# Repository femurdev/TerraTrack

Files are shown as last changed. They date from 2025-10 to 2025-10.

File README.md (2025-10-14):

# 🚀 TerraTrack
```
"""
AI-powered robotics project inspired by the game TerraTech.
Built for learning, experimentation, and competition.
"""
```

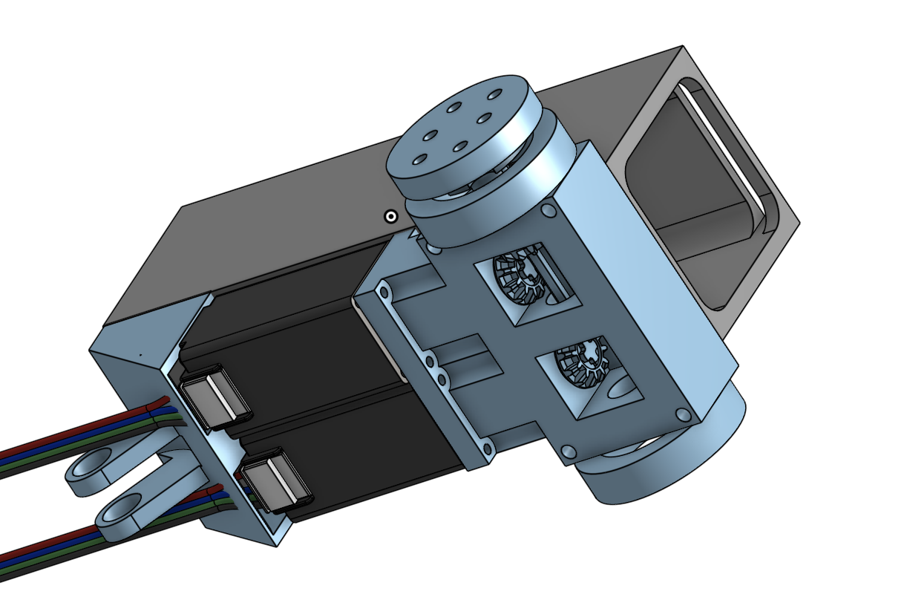
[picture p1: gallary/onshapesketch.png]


## 🧠 Overview

TerraTrack is an ongoing robotics project that explores the intersection of **AI**, **embedded systems**, and **mechanical design**.  
The goal is to create a modular, intelligent platform capable of running on both **ESP32** and the upcoming **Arduino × Qualcomm** systems.

While some design details are being kept private until the competition season wraps up, this repository captures the learning process, designs, and build journey so far.

## ⚙️ Current Focus

- 🤖 Basic AI-driven motion and control (early stage)
- ⚡ Compatibility across ESP32 and Arduino hardware
- 🧩 Modular mechanical design for quick rebuilds
- 🔧 Open workflow using Onshape + Blender
- 🔋 Safe custom power system with 3D-printed enclosure

## 🛠️ Build Journal

Read the full project journal on **Hack Club Blueprint**:  
👉 [TerraTrack Project Journal](https://blueprint.hackclub.com/projects/485)

Below is a summary of progress so far.

### 🧩 Early Prototyping (v1–v2)
- Designed and printed first chassis, gearbox, and axles using **Onshape** and **Blender**.
- Fought with 3D printers, burned out an early prototype, and learned about safe wiring.
- Added a toggle switch after discovering how easy it is to cause “accidental smoke.”

### ⚙️ Iteration & Redesign (v3–v4)
- Reinforced axles with skateboard bearings to prevent snapping.
- Added gearbox covers and improved weight distribution.
- Created a new battery pack with secure housing.
- Introduced a rear “butt” assembly for smoother movement.
- Countless printing and soldering sessions to get it all together.

### 🔥 Failure, Fatigue, and Fire
- Motor drivers finally responded after days of debugging—then failed again.
- Tried increasing torque through firmware; resulted in actual smoke.
- Damaged stepper motors and drivers, currently sourcing replacements.
- Despite the setbacks, communication and control logic now partially work.

## 🧰 Tools & Components

| Category | Tools / Components |
|---|---|
| CAD / Modeling | Onshape, Blender |
| Hardware | ESP32, TMC2209 Motor Drivers, Stepper Motors |
| Fabrication | 3D Printing (Da Vinci Jr., Bambu X1), Soldering |
| Software | Arduino IDE, C++ |
| Other | PLA Filament, Custom Battery Enclosure, Bearings |

## 💡 Lessons Learned

- Iteration is everything — no version is wasted.
- Documentation helps recover from mistakes faster.
- Always isolate power before soldering or testing.
- Fire safety isn’t optional.
- Building with limited resources teaches patience (and creativity).

## 🧭 Next Steps

- Rebuild chassis with stronger materials.
- Improve torque and motor control code.
- Add modular battery swapping and safety systems.
- Integrate AI motion logic once hardware is stable.
- Seek funding for replacement parts (~$120 total).

## 📷 Gallery

| Stage | Image |
|---|---|
| Gearbox v2 | Screenshot 2025-10-13 at 6.09.27 PM.png |
| Battery Pack v1 |  |
| Gearbox Rebuild | Screenshot 2025-10-13 at 9.15.03 PM.png |
| Final v2 Mockup |  |

## 💬 Author

TerraTrack is a student robotics project developed as part of a Hack Club event.  
The aim is to learn, experiment, and document the process honestly — including the mistakes, smoke, and all.  

Follow progress or share ideas via [Hack Club Blueprint](https://blueprint.hackclub.com/projects/485).

## ⚠️ Note

Some key parts of the system are withheld until after the competition season to prevent duplication.  
Full technical documentation will be released once the event concludes.

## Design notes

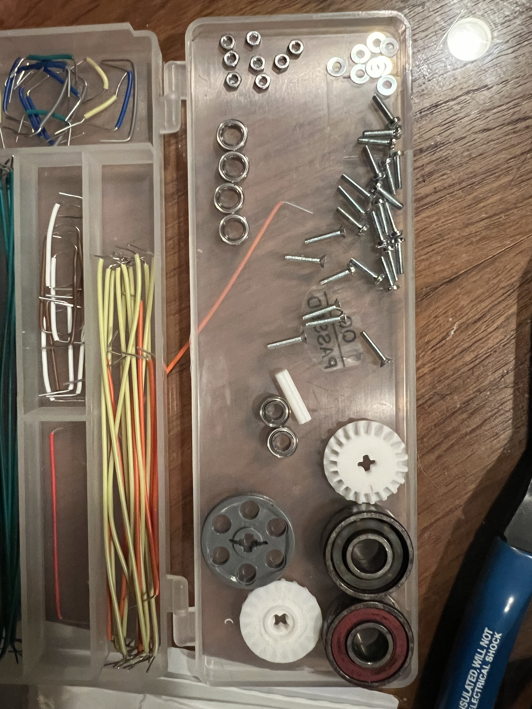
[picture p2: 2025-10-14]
gallary/hardware.jpeg

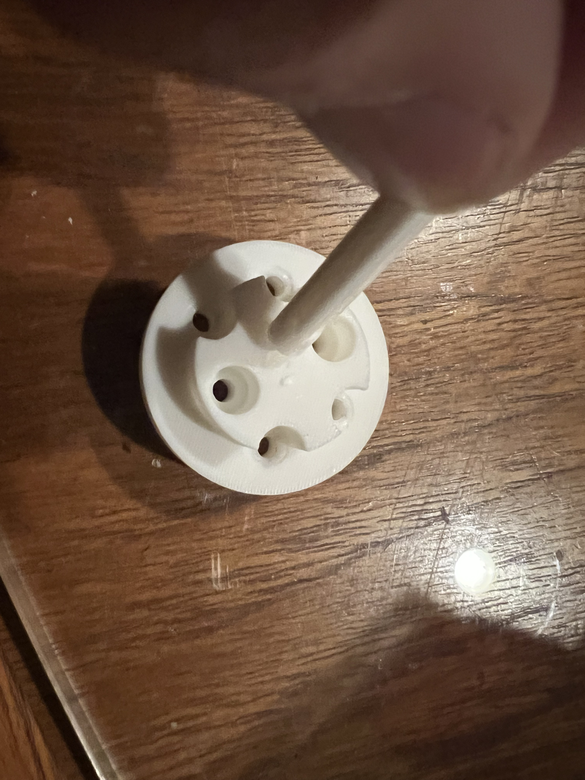
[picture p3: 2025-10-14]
gallary/brokenAxel.jpeg

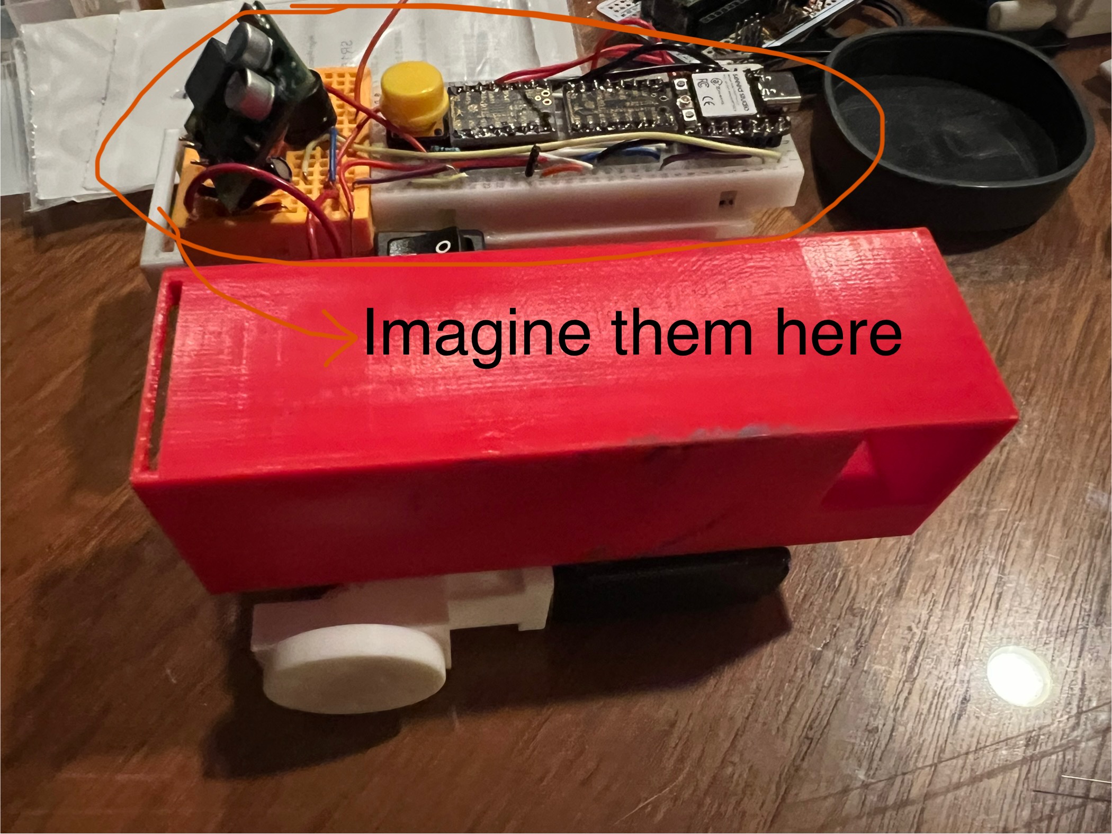
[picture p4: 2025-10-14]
gallary/finalv2.jpg

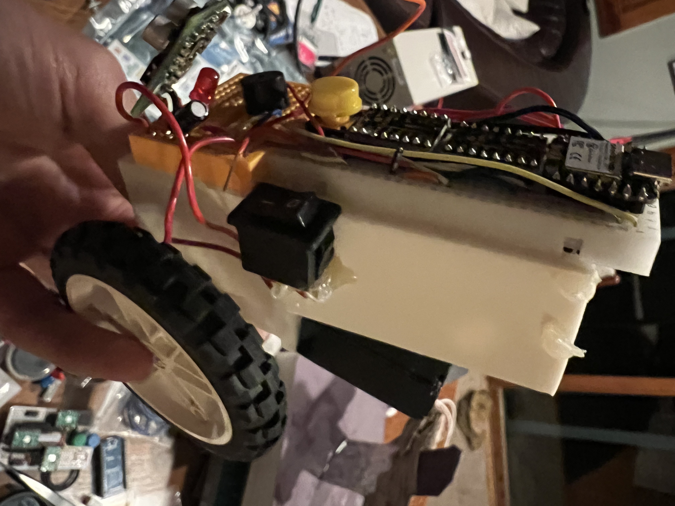
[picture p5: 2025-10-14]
gallary/recreation.jpeg

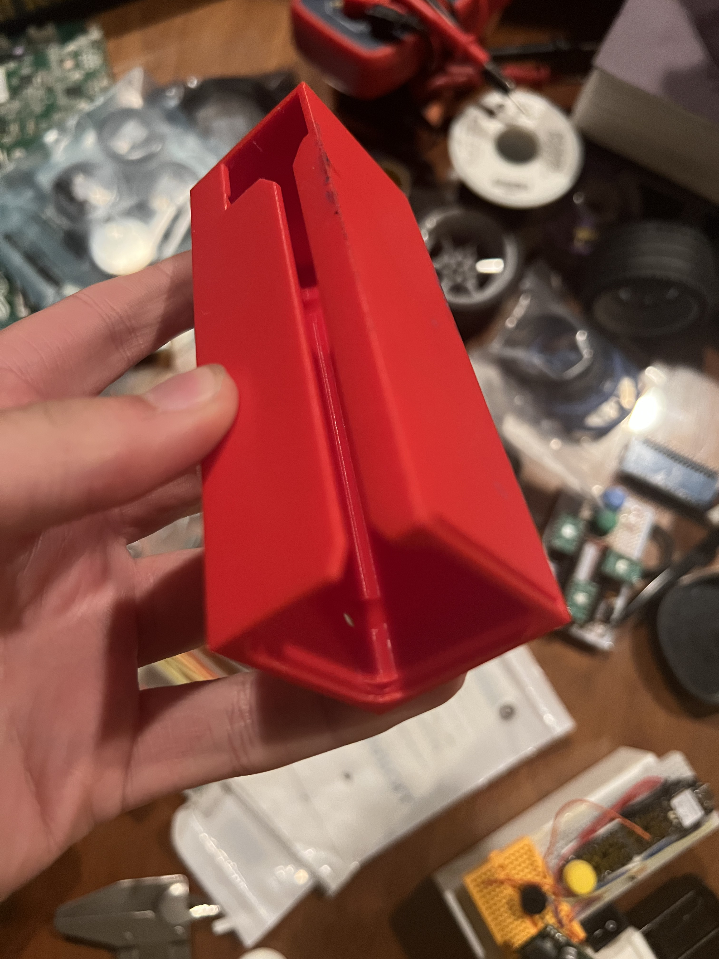
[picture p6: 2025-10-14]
gallary/battery2.jpeg

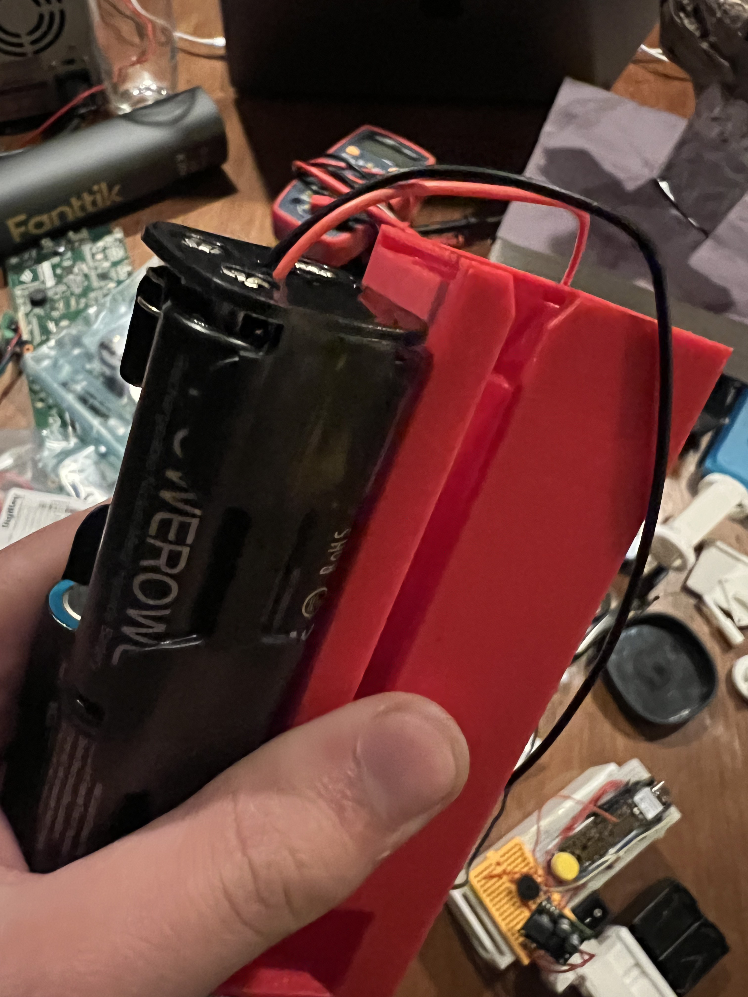
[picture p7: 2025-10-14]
gallary/battery1.jpeg

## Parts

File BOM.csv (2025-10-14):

Item | Quantity | Part Number | Description | Manufacturer | Vendor | Unit Price (USD) | Total Price (USD) | Notes | Product Link
1 | 2 | SS2421-5041 | Stepper Motor, Bipolar, 1.8°, 4.5V, 1.2A, 42mm Frame | Sanyo Denki | Digi-Key | 45.74 | 91.48 | Primary stepper motors | https://www.digikey.com/en/products/detail/sanyo-denki-sanmotion-products/SS2421-5041/13533469
2 | 2 | 3768 | DRV8434S SPI Stepper Motor Driver Carrier, 2A Max Current Limit | Pololu Robotics & Electronics | Pololu | 13.95 | 27.9 | Motor driver boards | https://www.pololu.com/product/3768
 |  |  | Total Estimated Cost (USD) |  |  |  | 119.38

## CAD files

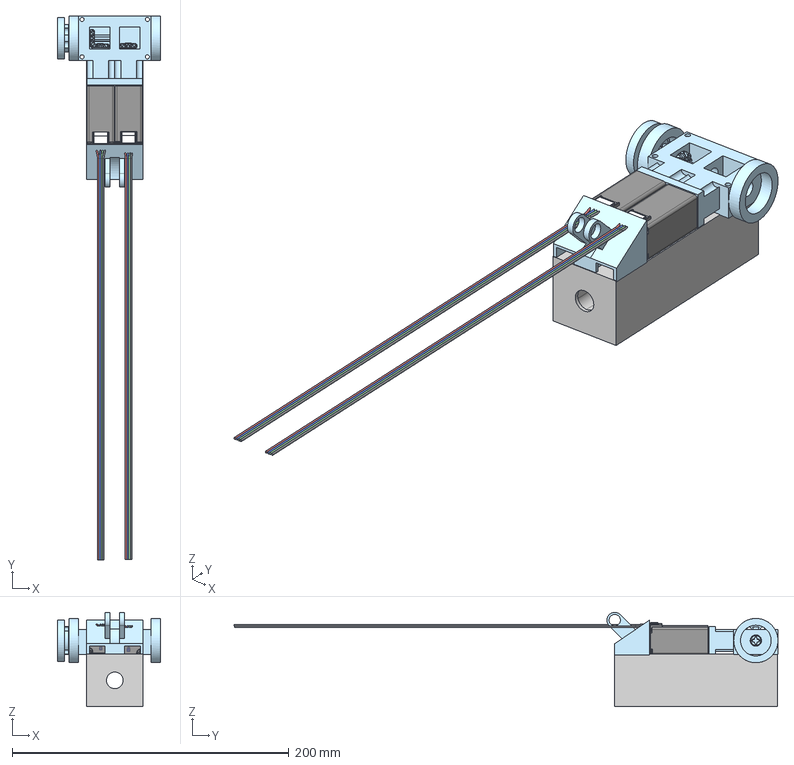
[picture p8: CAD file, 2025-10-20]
Assembly 1.step
74.5 x 393.2 x 68.1 mm
SY20STH42-0804A x 2

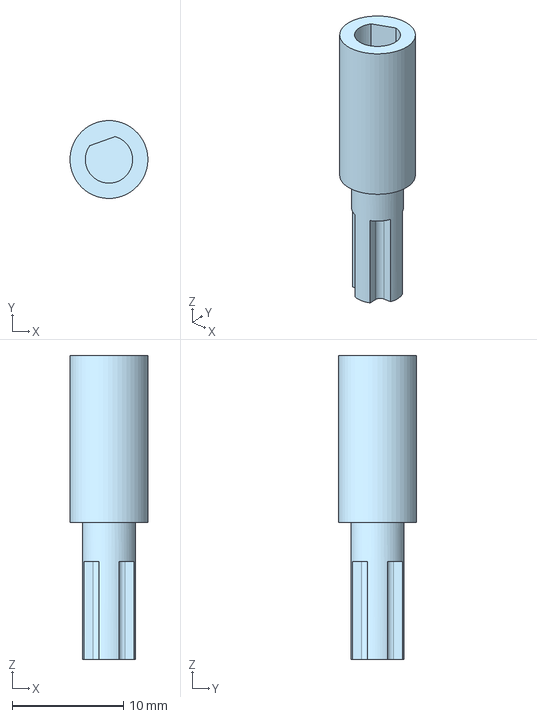
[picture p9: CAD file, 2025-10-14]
models/4vSTEPFiles/v4FinalMotorAdapter.step
6.99 x 7.00 x 27.3 mm

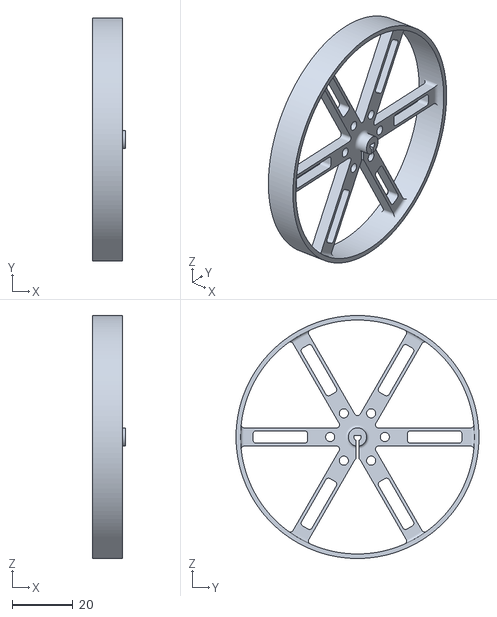
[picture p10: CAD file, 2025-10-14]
models/imports/Pololu wheel 90mm x 10mm - Pololu wheel 90mm x 10mm v1.stl
11.0 x 80.0 x 80.0

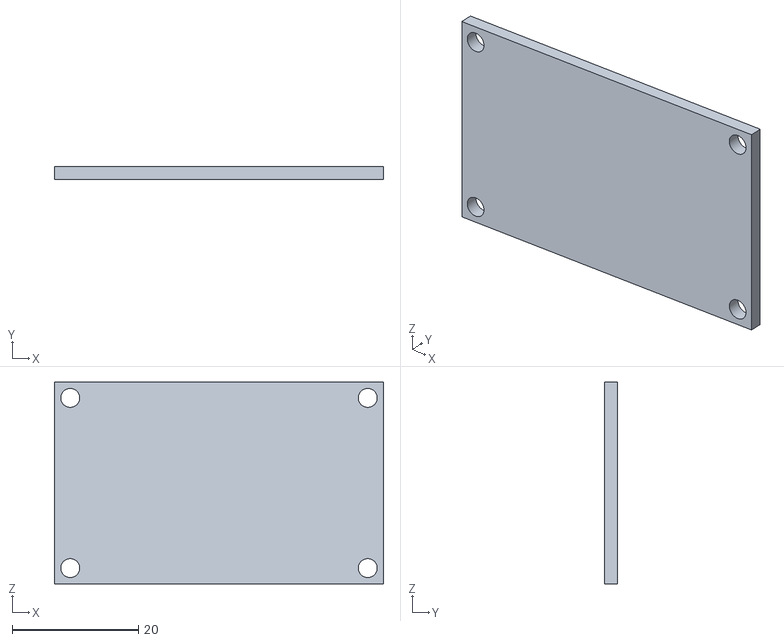
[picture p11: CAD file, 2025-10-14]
models/v4/v4gearcover.stl
52.2 x 2.00 x 32.0

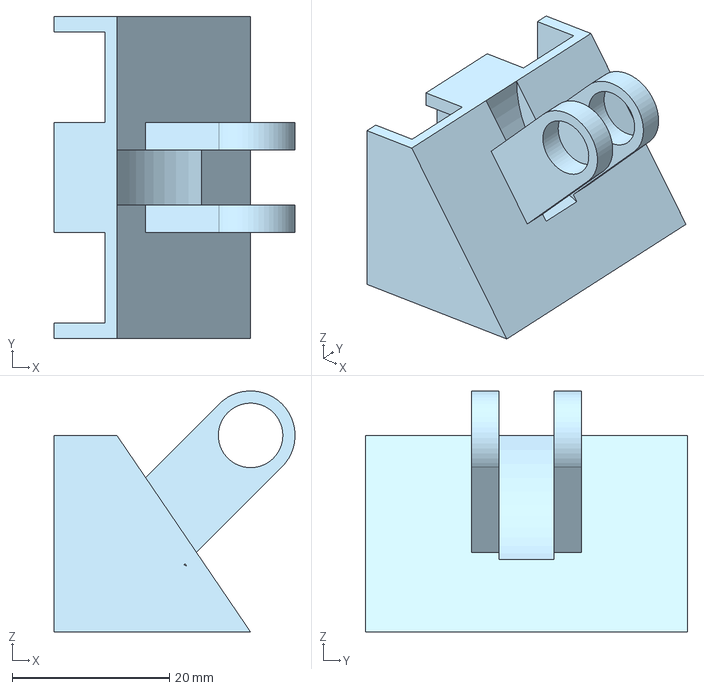
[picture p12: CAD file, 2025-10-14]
models/4vSTEPFiles/v4FinalButt.step
30.6 x 41.0 x 30.6 mm

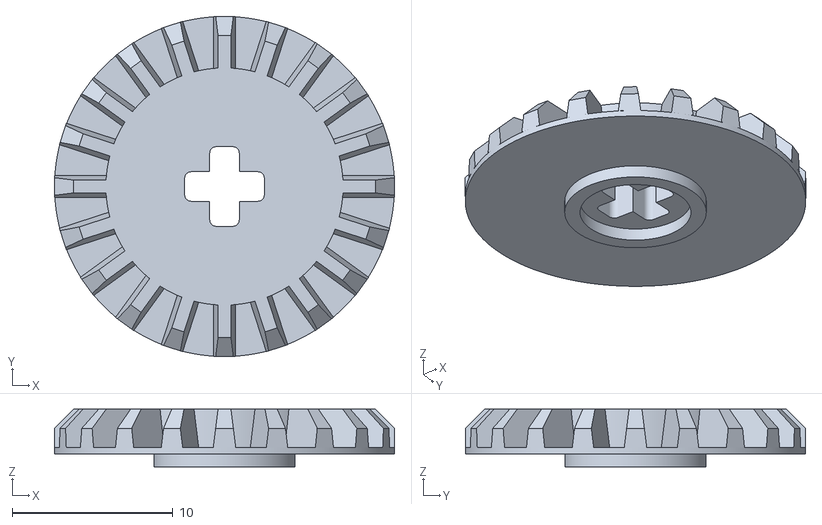
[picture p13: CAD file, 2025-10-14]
models/imports/20t.stl
21.2 x 21.2 x 3.60

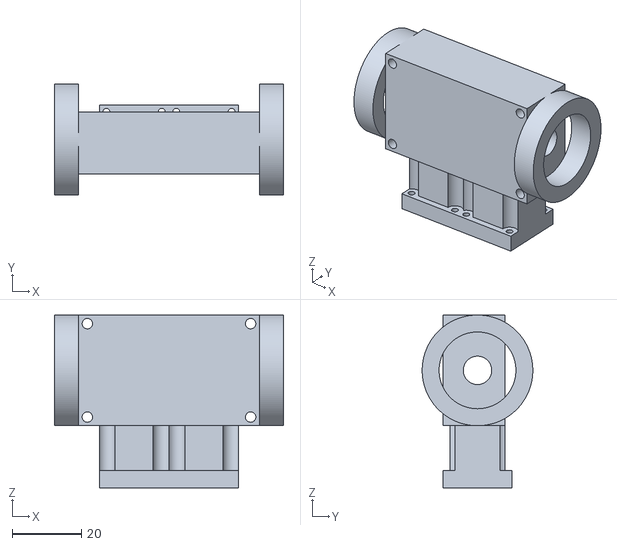
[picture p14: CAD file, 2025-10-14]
models/v4/v4gearbox.stl
66.2 x 32.0 x 50.0

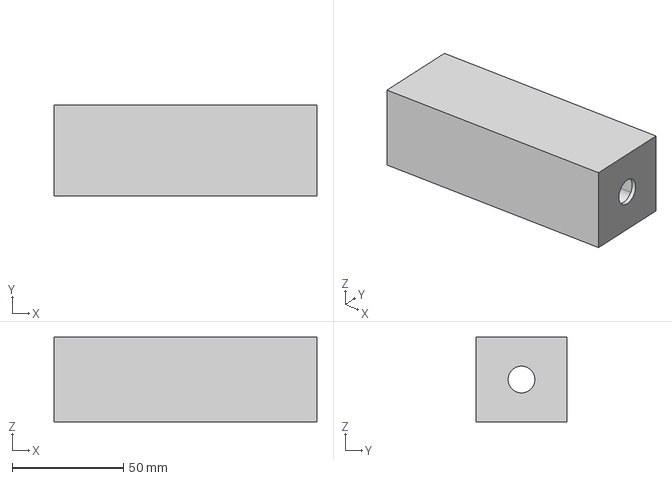
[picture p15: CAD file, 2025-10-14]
models/4vSTEPFiles/v4FinalBatteryHolder.step
118.0 x 41.0 x 38.0 mm

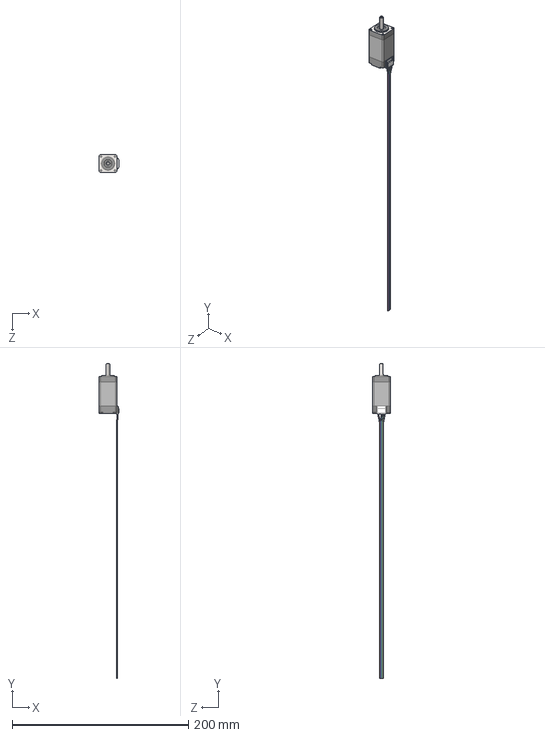
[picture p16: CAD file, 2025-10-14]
models/imports/SY20STH42-0804A.step
22.3 x 357.5 x 20.0 mm

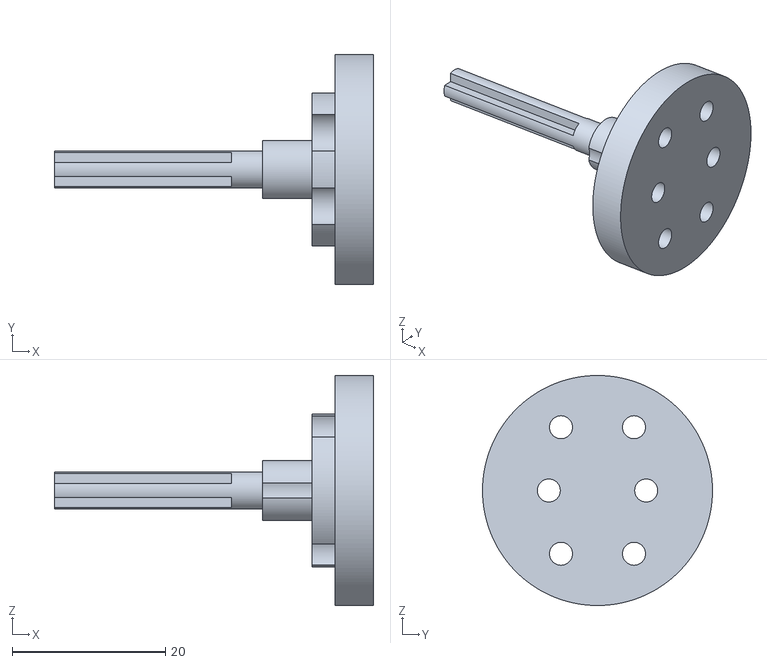
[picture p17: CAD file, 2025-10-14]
models/v4/v4wheel.stl
41.6 x 30.0 x 30.0

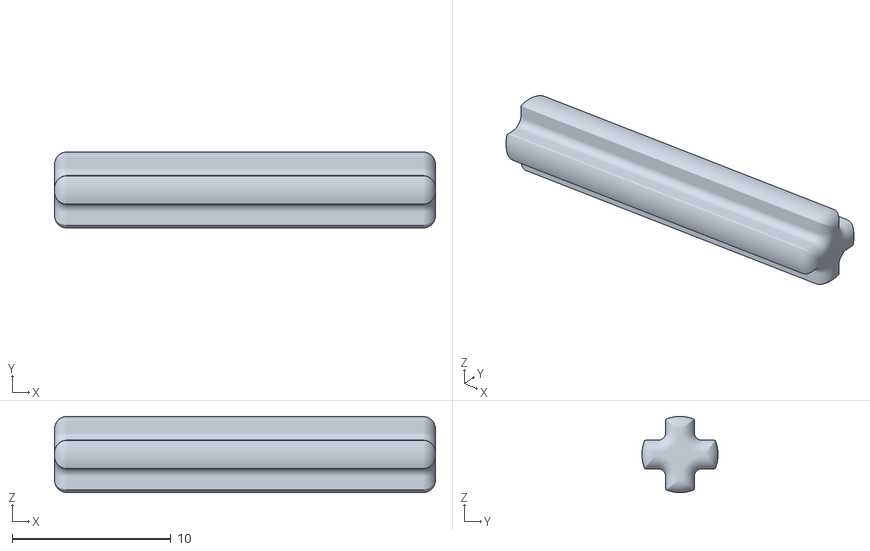
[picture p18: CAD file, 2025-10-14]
models/imports/4519 DkStone Technic Axle 3 - Part 1.stl
24.0 x 4.80 x 4.80

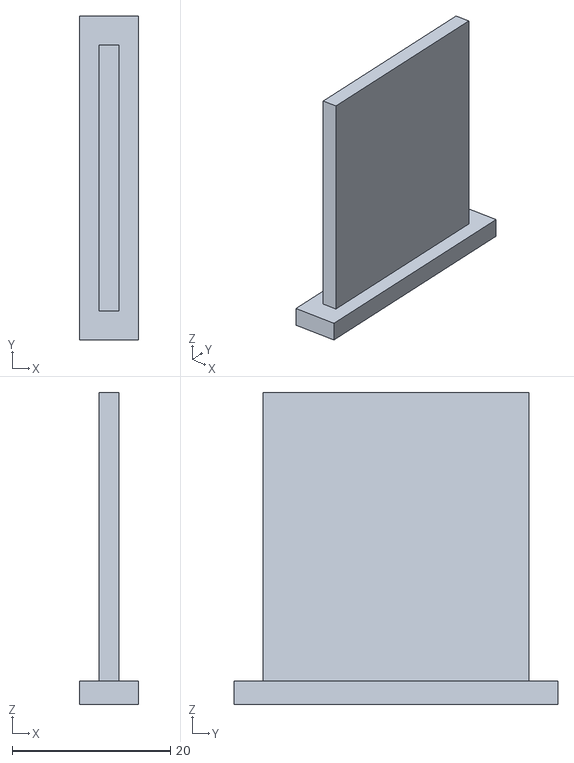
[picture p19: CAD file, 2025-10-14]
models/v4/v4battblock.stl
7.50 x 41.0 x 39.5

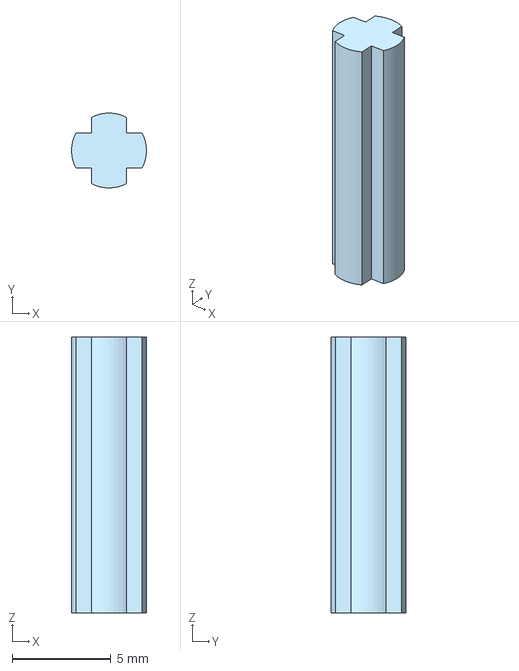
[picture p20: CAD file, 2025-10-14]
models/4vSTEPFiles/v4FinalShavedAxel(for butt).step
3.80 x 3.80 x 14.0 mm

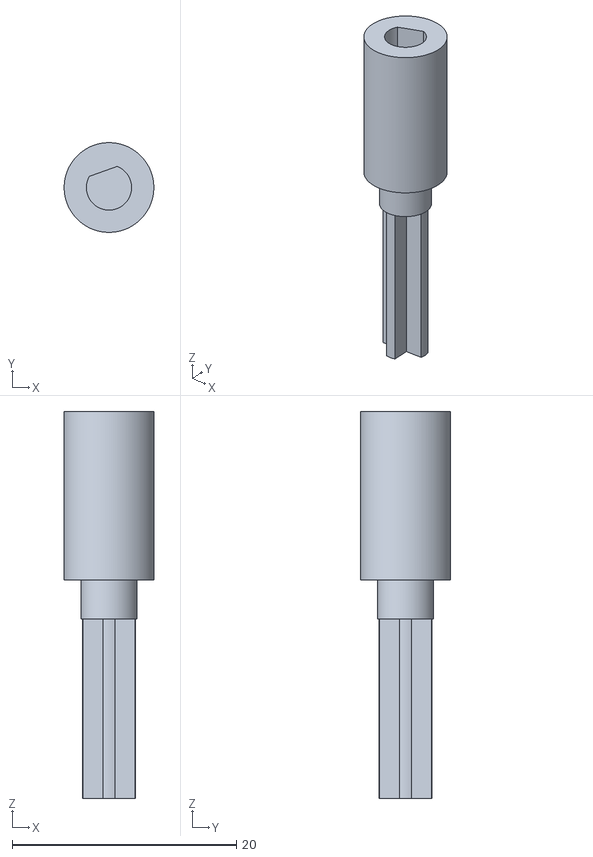
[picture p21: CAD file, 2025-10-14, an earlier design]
models/v1/yayayayaya.stl
8.00 x 8.00 x 34.5

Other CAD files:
models/4vSTEPFiles/v4FinalGearboxDoor.step
models/4vSTEPFiles/v4FinalAxel.step
models/4vSTEPFiles/v4FinalGearbox.step
models/4vSTEPFiles/v4FinalBatteryDoor.step
models/v1/Part Studio 1 - Part 1(6).stl
models/v1/Part Studio 1 - Part 1(7).stl
models/v1/Part Studio 2 - Part 1.stl
models/v1/Technic_Gear_Single-Sided.stl
models/v2/v2gearbox.stl
models/v2/v2mot.stl
models/v2/v2wheel.stl
models/v3/v3backaxel.stl
models/v3/v3batt.stl
models/v3/v3butt.stl
models/v3/v3wheel.stl

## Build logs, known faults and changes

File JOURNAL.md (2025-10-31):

<!--
  ===================    !!READ THIS NOTICE!!   ====================
  DO NOT edit this file manually. Your changes WILL BE OVERWRITTEN!
  This journal is auto generated and updated by Hack Club Blueprint.
  To edit this file, please edit your journal entries on Blueprint.
  ==================================================================
-->

## 10/16/2025 7:16 AM - Prototyping, routing, discovering, and lighting things fire.  

### Old Recount

This is to catch everyone up to the current state of things. I have mark one completed at this point but much to my dismay, it does not work. I have managed to burn it and can not afford any more components for the time being. 
## Here's a quick recap of what happened: 
Learned on shape and created v1 (and technically v2, but that was small). 
### Shopping and Physics: 
I ran some basic demos thing for my math. Look at what I have remaining from this step: Screenshot 2025-10-13 at 8.47.01 PM.png 
This translated to snooping arr round for parts shortly after, which is a headache to match steppers and motors. 
### Onshape & Blender!! Motor Connection v1 (3+ hours, I'm new to Onshape at this point): Screenshot 2025-10-13 at 6.07.49 PM.png Axel v1 (1 hour, getting better): Screenshot 2025-10-13 at 6.09.04 PM.png 
### Gearbox v2 
(2 hours again, multiple axies and offsets are hard for begining): 
Screenshot 2025-10-13 at 6.09.27 PM.png  The gearbox took some hardware too.  Battery container v1 (4 hours, I used blender to try it out, don't reccommend):   
### Fabrication.
The printer broke like 4 times, at this point and I tried to fix the sucker for 6+ hours (not included here for obvious reasons.) (da Vinci Jr. XYZ printer from the cretaceous) Off to the library to use their X1. Continued in CAD. Took an hour or so of changing nozzles and filament + glusticking. There were a few problems with this first batch. The most blaring is that the Axels repeatedly snapped. It was at some time at the 17-ish hour mark of this project when I started soldering my motor drivers and ESP32. This in of itself took two hours to find, set up, dismantle, and store. I was spending the next hour-ish gluing the parts together when suddenly, 
_Sparks!_ _Smoke!_ _Panic!_. 
I don't have a photo of this but imagine ElectroBoom strumming his electric guitar. I discovered that a talent of mine that made this fire followed me here, complete idiocy. I had left the barreries in the capsule while I contined making other parts of the setup. Lickily, nothing was destroyed but this made me realize the need for a switch. Jump to an hour later where I am found dismantling an old electronic board from I don't even know what. It had a toggle switch rated for 3 amps, good enough for me. Stay tuned for part 2 of the catch up, we're only 4 days (only about 23 hours of which were on this project) into this mess at this point. Here's a recreation of the state of the bot at the end of this. Sorry about this taking so much time, I'm juggling cleaning and teaching my brothers about electronics as I build this. Its part of a larger team event so there are also numerous hours of discussion not mentioned here.   

## 10/16/2025 7:17 AM - Solving problems and innovation (v3 & v4 of inital design)  

# Old Recount
We're off to the races. I've got a basic setup and body, but there's something nagging at me, my bot, and my soul: getting it working. I constructed the bot completely, top to bottom, complete with hot glue connections that would have outlived the sun. But it wasn't to be. Like all engineering endeavors, there was a laundry list of glaring issues, many of which I honestly thought I could ignore. Here, I think I'll do a picture by picture list of improvements that I made to my design: 
### The Axels. 
They look so thin and have just 3 mm of PLA Lego axel extrusion to hold them upright. Of course, they were going to snap. I added in some more joints and another 2 bearings onto the parts list, one for each side. Took about 4 hours to decide how to fix this and tear the bearings out of an old skateboard. Screenshot 2025-10-13 at 9.15.21 PM.png 
### The Gearbox. 
I dropped it on the floor and everything came out. Furthermore, I added a cover. Now, if it breaks, I won't know immediately (bad) and have the peace of mind that I haven't lost parts. (good) a couple of other things include the insane triple bearing design to try to take as much wight and distribute it as evenly as possible. (This is, and is still IMO valid madness) Each assembly took an hour and I did this a lot as I made changes. Screenshot 2025-10-13 at 9.15.03 PM.png 
### The Battery Pack. 
The battery pack that was initially made was too small for the pack once I actually added the batteries. There was no real other problem. I also added a cover so that way they can't fall out now. This took a bit to dseign. Screenshot 2025-10-13 at 9.15.48 PM.png 
### The Butt. 
Before, I didn't have any way for the car to drag itself along. This butt component allows me to add a Lego wheel and a few bearings to let the car glide seamlessly over the floor. I used layer designing for this, and it worked to an absolute charm, except for the fact that it was completely new to me and therefore took about 3 hours to perfect once I settled on an idea. Screenshot 2025-10-13 at 9.17.05 PM.png 
### Fabrication. 
3D printing once again took ages and soldering it a pain as always. I got the circuit back together, transferred bodies and put enough glue to make the gods envy it. To clear up any confusion between v3 and v4, v3 was when I added the bearing and nothing else. 4v came just after and was much more intense of a rebuild so that is what is here. ### Gearboxes are impossible! Sorry for having to say this again, they just take _SEVERAL HOURS_ to assemble each and every time. I dislike this very much. 
### OMG ITS PROGRAMMING, EVERYBODY RUN!!! 
I normally love programming, but there's something about this particular project that just made it impossible. I don't know what was about these particular motor drivers, but I can't get them to even budge. Furthermore, I found a sneaky pin that I needed jumpers for, but even that didn't solve my problems. Sorry, no complete assembly because I dismantled it and want to save the recreation of it for my next post. This took the **majority of my time this week**, even during school, where I wrote potential interactions that I only hoped would work. Well, that was awful. I'd just sunk a whole week and a half into this thing, and I'm stumped. No Fires this time (1 nature — 1 me)  

## 10/16/2025 7:18 AM - Failure, Fatigue, and Fire  

## Old Recount
This is the final update to get you up to speed on this project. _**Finally**_ But it isn't over. 
### The changes.
The whole thing is dismantled. Seriously. Let me elaborate. When I last left off on this story, I was still discussing the fact that I was stuck on programming this sucker. Well, after another two days when I told myself, just one more try, just one more try, MAGIC. The motors suddenly locked up. 
### What this means. 
This means that I have successfully told my motor controllers to turn on. _Big whoop!_ 
Seriously, this is what I couldn't get my motors to do for the past two weeks at this point. Now, they were awaiting commands, commands that were no longer hours to debug why it wasn't connecting, just commands that would work now that the communication was working. So I told them to spin in one circle while I held the bot in the air. They did that. I put it on the gound. 
_*crickets*_ 
I heard nothing. The motors tuned out to either be too weak to actually tun the wheels or something much worse is happening (that to this that I don't know). I used much of my remaining time that day trying to get it to move. The next day, I continued, I brought it home, I did everything. 
_It. Wouldn't. Budge._ 
I read online that adding some code could make them stronger:
```
  driver1.setup(Serial1, SERIAL_BAUD, TMC2209::SERIAL_ADDRESS_0, UART_PIN, UART_PIN);
  driver1.setRunCurrent(100);
  driver1.setHoldCurrent(0);
  driver1.setMicrostepsPerStep(1);       // full step for max torque
  driver1.disableStealthChop();          // spreadCycle = stronger torque
  driver1.enable();
```
### Big mistake.
The thing started smoking as soon as I tuned it on, slowly at first, then pluming outwards. The robot had lost the magic smoke. We all know what that magic smoke means. Someone, on board, has died. Most of the time, only the factory can put said magic smoke back inside the components, and I know this truth. 
_Small issue:_ the components that burned out were the only steppers I had, which cost 60 dollars before tariffs but are now 120 dollars. I have a plan now to avoid this insane bill, but I still need the funding for this project. I have 2 motors that cost 40 dollars each and 2 drivers that sum to 40 dollars, about 120 in total. The new chassis requires a new roll of filament to make. Please help I'll leave you with this recreation:   

## 10/18/2025 12:55 PM - Ideation, Shopping, and Physics  

### Old Recount - handwritten this time. (feels like walking into engineering English class)
This is to catch everyone up to the current state of things. I have mark one completed at this point but much to my dismay, it does not work. I have managed to burn it and can not afford any more components for the time being. Here's a quick recap of what happened.
Learned Onshape and created v1 (and technically v2, but that was small adjustments). 

### Shopping and Physics: 
I ran some basic demos thing for my math. Look at what I have remaining from this step: Screenshot 2025-10-13 at 8.47.01 PM.png 
This translated to snooping around for parts shortly after, which is a headache to match steppers and motors. 

## 10/18/2025 12:55 PM - Onshape!!  

I began my development by creating a d-shaft to Lego axel connection. My plan was to use bevel gears from a Lego kit to translate the motion from the motors 90 degrees. I swear that my sketches are valid, but it just don’t care. I listed everything out but hack club wants me to spit it up, so here we go!

### Motor Connection v1 (3 hours as I'm new to Onshape at this point): 

Screenshot 2025-10-13 at 6.07.49 PM.png 

## 10/18/2025 1:01 PM - Continued development  

### Axel v1: 

I continued uncovering how to use Onshape and came up with this design. When I first made it, I don’t know how I missed the glaring issue that the axle is so thin. This was updated in a later revision, but _still_. Additionally, this revision relied only on one bearing, something that I still don’t believe that I did.  
Screenshot 2025-10-13 at 6.09.04 PM.png 

## 10/18/2025 1:02 PM - Again, more Onshape yet  

I continued to work on fleshing out this idea. I was gaining traction on how to use Onshape at this point.

### Gearbox v1

4 hours again, multiple axis and offsets are hard for beginning users. I come from a background of blender and animation models, not CAD beyond Tinkercad. I used to build my projects purely off of blender and other files, but that is just impossible for me sometimes.  
Screenshot 2025-10-13 at 6.09.27 PM.png    

## 10/18/2025 1:02 PM - Hardware  

The gearbox took some hardware too. Most of this was scavenged from some old projects, skateboards, and even from an old 3d printer. These include bearings, some screws and the switch for the bot (not pictured.) This was a quick process all except for the hour and a half trip up to ace hardware form $6 of M2 screws.    

## 10/18/2025 1:03 PM - Battery Pack  

Battery container v1- 4 hours, I made this when I originally leaned blender to try it out, don't recommend for engineering models. I redesigned the model in Onshape after 4 hours of fooling around in blender. Keep in mind I still haven’t actually printed any of this.    

## 10/18/2025 1:21 PM - Da Vinci v. Me / Praying for an X1  

The printer broke like 4 times, at this point, and I tried to fix the sucker for over 2 days. (not included here for obvious reasons.) (da Vinci Jr. XYZ printer from the Cretaceous) Off to the library to use their X1.  (Just to let you know, it printed like a charm.) Everything went smoothly.  
Here’s what it's supposed to look like:  

And mine:


## 10/18/2025 1:22 PM - Fabrication & Fire  

Took an hour or so of changing nozzles and filament \+ sticking. Came back and got the parts later. There were a few problems with this first batch. The most blaring is that the Axels repeatedly snapped. It was at some time at the 20-ish hour mark of this project when I started soldering my motor drivers and ESP32. This in of itself took two hours to find, set up, dismantle, and store. I was spending the next hour gluing the parts together when suddenly,   
_Sparks!_ _Smoke!_ _Panic!_.   
I don't have a photo of this but imagine ElectroBoom strumming his electric guitar. I discovered that a talent of mine that made this fire followed me here, complete idiocy. I had left the barreries in the capsule while I continued making other parts of the setup. Luckily, nothing was destroyed, but this made me realize the need for a switch. Jump to an hour later, where I am found dismantling an old electronic board from I don't even know what. It had a toggle switch rated for 3 amps, good enough for me. Here's a recreation of the state of the bot at the end of this. Sorry about this taking so much time, I'm juggling cleaning and teaching my brothers about electronics as I build this. Its part of a larger team event so there are also numerous hours of discussion not mentioned here.     

## 10/18/2025 1:23 PM - Innovation - The Axel  

### This is a recount of what happened.

We're off to the races. I've got a basic setup and body, but there's something nagging at me, my bot, and my soul: getting it moving. I constructed the bot completely, top to bottom, complete with hot glue connections that would have outlived the sun. But it wasn't to be. Like all engineering endeavors, there was a laundry list of glaring issues, many of which I honestly thought I could ignore. Here, I think I'll do a picture by picture list of improvements that I made to my design (Hackclub Bluprint wants me to spit these up, so this post only includes the first one):   
### The Axels.   
They look so thin and have just 3 mm of PLA Lego axel extrusion to hold them upright. Of course, they were going to snap. I added in some more joints and another 2 bearings onto the parts list, one for each side. Took about 4 hours to decide how to fix this and tear the bearings out of an old skateboard. Screenshot 2025-10-13 at 9.15.21 PM.png   

## 10/18/2025 1:23 PM - Innovation - The Gearbox.  

I dropped it on the floor and everything came out. Thus, I added a cover. Now, if it breaks, I won't know immediately (bad) and have the peace of mind that I haven't lost parts (good.) A couple of other things include the insane triple bearing design to try to take as much wight and distribute it as evenly as possible. (This is, and is still IMO valid madness) Each assembly took an hour and I did this a lot as I made changes. Screenshot 2025-10-13 at 9.15.03 PM.png   

## 10/18/2025 1:24 PM - Innovation - The Battery Pack.  

The battery pack that was initially made was too small for the pack once I actually added the batteries. There was no real other problem. I also added a cover so that way they can't fall out now. This took a bit to quite a bit of time in order to design. Screenshot 2025-10-13 at 9.15.48 PM.png 

## 10/18/2025 1:24 PM - Innovation - The Butt. - 3 hr  

Before, I didn't have any way for the car to drag itself along. This butt component allows me to add a Lego wheel and a few bearings to let the car glide seamlessly over the floor. I used layer designing for this, and it worked to an absolute charm, except for the fact that it was completely new to me and therefore took about 3 hours to perfect once I settled on an idea. Screenshot 2025-10-13 at 9.17.05 PM.png  

## 10/18/2025 1:27 PM - Innovation - Fabrication.  

3D printing once again took a trip and soldering it a pain as always. I got the circuit back together, transferred bodies and put enough glue to make the gods envy it. To clear up any confusion between v3 and v4, v3 was when I added the bearing and nothing else. 4v came just after and was much more intense of a rebuild so that is what is here. 

### Gearboxes are impossible! 

Sorry for having to say this again, they just take _SEVERAL HOURS_ to assemble each and every time. I dislike this very much. 
Screenshot 2025-10-18 at 1.27.27 PM.png

## 10/18/2025 1:29 PM - OMG ITS PROGRAMMING, EVERYBODY RUN!!!  

I normally love programming, but there's something about this particular project that just made it impossible. I don't know what was about these particular motor drivers, but I can't get them to even budge. Furthermore, I found a sneaky pin that I needed jumpers for, but even that didn't solve my problems. Sorry, no complete assembly because I dismantled it and want to save the recreation of it for my next post. This took the \*\*majority of my time this week\*\*, even during school, where I wrote potential interactions that I only hoped would work. Well, that was awful. I'd just sunk a whole week and a half into this thing, and I'm stumped. No Fires this time (1 nature — 1 me).  
Here’s a photo of the madness at this time:


## 10/18/2025 1:30 PM - Big Changes, Big Issues & Big Plans  

The entire thing has dismantled. Seriously. Let me elaborate. When I last left off on this story, I was still discussing the fact that I was stuck on programming this sucker. Well, after another two days when I told myself, just one more try, just one more try, MAGIC. The motors suddenly locked up. 

### What this means. 

This means that I have successfully told my motor controllers to turn on. _Big whoop!_   
Seriously, this is what I couldn't get my motors to do for the past two weeks at this point. Now, they were awaiting commands, commands that were no longer hours to debug why it wasn't connecting, just commands that would work now that the communication was working. So I told them to spin in one circle while I held the bot in the air. They did that. I put it on the gound.   
_\*crickets\*_   
I heard nothing. The motors tuned out to either be too weak to actually tun the wheels or something much worse is happening (that to this that I don't know). I used much of my remaining time that day trying to get it to move. The next day, I continued, I brought it home, I did everything.   
*It. Wouldn't. Budge.*   
I read online that adding some code could make them stronger:  
```  
  driver1.setup(Serial1, SERIAL_BAUD, TMC2209::SERIAL_ADDRESS_0, UART_PIN, UART_PIN);  
  driver1.setRunCurrent(100);  
  driver1.setHoldCurrent(0);  
  driver1.setMicrostepsPerStep(1);       // full step for max torque  
  driver1.disableStealthChop();          // spreadCycle \= stronger torque  
  driver1.enable();  
```

### Big mistake.

The thing started smoking as soon as I tuned it on, slowly at first, then pluming outwards. The robot had lost the magic smoke. We all know what that magic smoke means. Someone, on board, has died. Most of the time, only the factory can put said magic smoke back inside the components, and I know this truth.   
_Small issue:_ the components that burned out were the only steppers I had, which cost 60 dollars before tariffs but are now 120 dollars. I have a plan now to avoid this insane bill, but I still need the funding for this project. I have 2 motors that cost 40 dollars each and 2 drivers that sum to 40 dollars, about 120 in total. The new chassis requires a new roll of filament to make, but I got a spare. I'll leave you with this recreation:   

## 10/19/2025 - Assembly  

Created assembly and added it to repo. The parts are arranged correctly and everything is in place as it should be. I also downgraded this to a tier 3 project as per @CAN's feedback. I will cover the difference, as I was able to get this far without funding.
Screenshot 2025-10-19 at 9.33.32 PM.png

## 10/31/2025 - Quick Update  

Hey yall'

School's going crazy before the end of the second marking period so there isn't much progress. Also, I need to wait for parts to ship. I bought my own parts from bane bot without the grant. Will see where this goes when I get the wheels. Spent about 30 minute pricing out wheels between last and this update from Bane Bot.

P.S. I just discovered some really cool hardware for other projects, & ADHD is going to go crazy. Please pardon the excitement and delay. I'll get back on this after Nov 2nd when my stuff is due.

T61P-193BG__90399

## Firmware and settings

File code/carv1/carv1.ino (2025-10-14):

#include <TMC2209.h>

TMC2209 driver1;
TMC2209 driver2;

// === Pins ===
#define STEP1 D1
#define DIR1  D2
#define EN1   D0
#define STEP2 D4
#define DIR2  D5
#define EN2   D3
#define UART_PIN D6

const long SERIAL_BAUD = 115200;
const uint8_t RUN_CURRENT_PERCENT = 100;   // 100% power
const uint8_t HOLD_CURRENT_PERCENT = 0;    // 0% hold current

const int STEP_DELAY_US = 5000;  // step speed
const long TOTAL_STEPS = 4000;  // how far to go

void setup() {
  Serial.begin(115200);
  delay(1000);
  Serial.println("=== MAX POWER MODE ===");

  Serial1.begin(SERIAL_BAUD, SERIAL_8N1, UART_PIN, UART_PIN);

  // === DRIVER 1 ===
  driver1.setup(Serial1, SERIAL_BAUD, TMC2209::SERIAL_ADDRESS_0, UART_PIN, UART_PIN);
  driver1.setRunCurrent(RUN_CURRENT_PERCENT);
  driver1.setHoldCurrent(HOLD_CURRENT_PERCENT);
  driver1.setMicrostepsPerStep(1);       // full step for max torque
  driver1.disableStealthChop();          // spreadCycle = stronger torque
  driver1.enable();

  // === DRIVER 2 ===
  driver2.setup(Serial1, SERIAL_BAUD, TMC2209::SERIAL_ADDRESS_1, UART_PIN, UART_PIN);
  driver2.setRunCurrent(RUN_CURRENT_PERCENT);
  driver2.setHoldCurrent(HOLD_CURRENT_PERCENT);
  driver2.setMicrostepsPerStep(1);
  driver2.disableStealthChop();
  driver2.enable();

  // === Control pins ===
  pinMode(EN1, OUTPUT); digitalWrite(EN1, LOW); // active low
  pinMode(EN2, OUTPUT); digitalWrite(EN2, LOW);
  pinMode(DIR1, OUTPUT); digitalWrite(DIR1, HIGH);
  pinMode(DIR2, OUTPUT); digitalWrite(DIR2, HIGH);
  pinMode(STEP1, OUTPUT);
  pinMode(STEP2, OUTPUT);

  Serial.println("Drivers armed for full power!");
  delay(500);
}

void loop() {
  // move forward
  for (long i = 0; i < TOTAL_STEPS; i++) {
    digitalWrite(STEP1, HIGH);
    digitalWrite(STEP2, HIGH);
    delayMicroseconds(2);
    digitalWrite(STEP1, LOW);
    digitalWrite(STEP2, LOW);
    delayMicroseconds(STEP_DELAY_US);
  }

  Serial.println("Done.");
}

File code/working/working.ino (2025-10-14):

#include <TMC2209.h>

// Create two driver instances
TMC2209 driver1;
TMC2209 driver2;

// Pin configuration
const int UART_PIN = D6;   // Shared PDN_UART (GPIO21)
const int EN1_PIN  = D0;   // Enable for driver 1
const int EN2_PIN  = D3;   // Enable for driver 2 (new)
const int STEP1_PIN = D1;  // Step for driver 1
const int DIR1_PIN  = D2;  // Dir for driver 1
const int STEP2_PIN = D4;  // Step for driver 2
const int DIR2_PIN  = D5;  // Dir for driver 2

const long SERIAL_BAUD = 115200;

// Current settings
const uint8_t RUN_CURRENT_PERCENT = 100;
const uint8_t HOLD_CURRENT_PERCENT = 0;

// Delay between mode switches
const int DELAY_MS = 4000;

void setup() {
  Serial.begin(115200);
  delay(1000);
  Serial.println("Starting dual TMC2209 on XIAO ESP32-C3...");

  // Initialize UART (half-duplex)
  Serial1.begin(SERIAL_BAUD, SERIAL_8N1, UART_PIN, UART_PIN);

  // --- Driver 1 setup ---
  driver1.setup(Serial1, SERIAL_BAUD, TMC2209::SERIAL_ADDRESS_0, UART_PIN, UART_PIN);
  driver1.setRunCurrent(RUN_CURRENT_PERCENT);
  driver1.setHoldCurrent(HOLD_CURRENT_PERCENT);
  driver1.enable();

  // --- Driver 2 setup ---
  driver2.setup(Serial1, SERIAL_BAUD, TMC2209::SERIAL_ADDRESS_1, UART_PIN, UART_PIN);
  driver2.setRunCurrent(RUN_CURRENT_PERCENT);
  driver2.setHoldCurrent(HOLD_CURRENT_PERCENT);
  driver2.enable();

  // Configure motion control pins
  pinMode(STEP1_PIN, OUTPUT);
  pinMode(DIR1_PIN, OUTPUT);
  pinMode(EN1_PIN, OUTPUT);
  digitalWrite(EN1_PIN, LOW); // Enable driver 1

  pinMode(STEP2_PIN, OUTPUT);
  pinMode(DIR2_PIN, OUTPUT);
  pinMode(EN2_PIN, OUTPUT);
  digitalWrite(EN2_PIN, LOW); // Enable driver 2

  driver1.setStandstillMode(driver1.NORMAL);
  driver2.setStandstillMode(driver2.NORMAL);

  Serial.println("Both TMC2209 drivers initialized successfully!");
}

void loop() {
  // Cycle through different standstill modes on both drivers
  Serial.println("Standstill mode = NORMAL");
  driver1.setStandstillMode(driver1.NORMAL);
  driver2.setStandstillMode(driver2.NORMAL);
  delay(DELAY_MS);

  Serial.println("Standstill mode = FREEWHEELING");
  driver1.setStandstillMode(driver1.FREEWHEELING);
  driver2.setStandstillMode(driver2.FREEWHEELING);
  delay(DELAY_MS);

  Serial.println("Standstill mode = STRONG_BRAKING");
  driver1.setStandstillMode(driver1.STRONG_BRAKING);
  driver2.setStandstillMode(driver2.STRONG_BRAKING);
  delay(DELAY_MS);

  Serial.println("Standstill mode = BRAKING");
  driver1.setStandstillMode(driver1.BRAKING);
  driver2.setStandstillMode(driver2.BRAKING);
  delay(DELAY_MS);

  Serial.println();
}
